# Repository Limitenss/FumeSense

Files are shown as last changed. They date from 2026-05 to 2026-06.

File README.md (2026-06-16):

# FumeSense

## Reviewer Message: please view the f3z file instead of the f3d, it contains the fully assembled case.

The FumeSense smart fume extractor is powered by an ESP32-S3. It features an Adafruit BME688 sensor that instantly detects harmful VOCs and activates a high-pressure fan to pull the fumes through an activated carbon filter. It also displays real-time data on a 2.4-inch LCD dashboard.

## Core Features

* **Auto-Detect & Remove:** Uses a gas to monitor the air. The moment VOCs from solder flux are detected, the system automatically ramps up the fan speed.
* **Hands-Free:** Both of your hands stay completely occupied with your soldering iron and components.
* **Filter Optimization:** Running a fan at 100% all the time unnecessarily wastes the active carbon compound by filtering clean room air. The auto-detect & remove feature ensures the carbon is only working when required, maximizing filter life.
* **Dashboard:** Features a Waveshare 2.4-inch LCD Module that displays fan-speed, and air info.
* **Manual Override:** Includes up and down buttons to let you instantly change the fan speed if you want to override the auto fan-speed.
* 

|Category |Component |Specific Model |Qty|Estimated Cost|Purpose |Link |
|---|---|---|---|---|---|---|
|Electronics |Microcontroller |Waveshare ESP32-S3-DEV-KIT-N8R8 |1  |$9.99 |Central brain; native pins avoid splicing |https://www.waveshare.com/esp32-s3-dev-kit-n8r8.htm?sku=24363 |
|Electronics |Display |Waveshare 2.4-inch LCD Module (240x320) |1  |$11.99 |Dashboard screen |https://www.waveshare.com/2.4inch-lcd-module.htm |
|Electronics |Air Quality Sensor |Adafruit BME688 |1  |$19.95 |Detects VOCs to trigger fan speed |https://www.adafruit.com/product/5046 |
|Airflow & Power |Extractor Fan |Noctua NF-F12 iPPC 3000 PWM, Heavy Duty Cooling Fan, 4-Pin, 3000 RPM (120mm, Black) |1  |$29.95 |Pulls fumes through filter |https://www.amazon.com/Noctua-NF-F12-iPPC-3000-PWM/dp/B00KFCRATC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|
|Airflow & Power |Filter Media |130x130x10mm Activated Carbon Sponge |1  |$8.54 |Traps solder flux |https://www.aliexpress.us/item/3256803786725180.html |
|Airflow & Power |Power Input |Adafruit Round Panel Mount Ext. Cable (30cm) |1  |$4.95 |Easy 24mm case mounting |https://www.adafruit.com/product/5607 |
|Airflow & Power |Power Splitter |5.5x2.1mm Female to Screw Terminal |1  |$3.99 |Splits 12V to fan and buck converter |https://www.amazon.com/Connector-Barrel-Adapter-Security-Camera/dp/B09S3S6RYC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 |
|Airflow & Power |Step-Down Converter |LM2596 DC-DC Buck Converter |1  |$7.99 |Drops 12V to 5V for ESP32 |https://www.amazon.com/Seloky-Converter-Adjustable-Electronic-Stabilizer/dp/B0DBVYP91F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 |
|Airflow & Power |Power Supply |12V DC Wall Adapter (2A) |1  |$7.97 |Main power source |https://www.amazon.com/Adapter-100-240V-Transformer-Charger-Security/dp/B091XSVV1Y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 |
|Hardware & Enclosure|Filament |PLA |1  |Owned |case material | |
|Hardware & Enclosure|Mounting Screws |M2 brass heat-set inserts |1  |$2.88 |Mounting Screws for Adafruit BME688 |https://www.aliexpress.us/item/3256805885174058.html |
|Hardware & Enclosure|Fan Inserts |M3 x 5mm Brass Heat-Set Inserts |4  |$5.95 |Anchors 120mm fan |https://www.adafruit.com/product/4255 |
|Hardware & Enclosure|Screen Inserts |M2.5 x 4mm Brass Heat-Set Inserts |4  |$7.39 |Mounts the 2.4-inch display |https://www.amazon.com/uxcell-Knurled-Printing-Threaded-Embedment/dp/B0CTCRQ94S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 |
|Hardware & Enclosure|Fan Screws |M3 x 30mm Socket Head Screws |4  |$9.99 |Clamps fan into M3 inserts |https://www.amazon.com/Alloy-Steel-Socket-Screws-Black/dp/B00W97RHMQ?th=1 |
|Hardware & Enclosure|Short Mounting Screws |M3 x 6mm Socket Head Screws |4  |$8.49 |Shallow mounting for case panels/accessories|https://www.amazon.com/Socket-Screws-Metric-Stainless-Machine/dp/B08976JTRX |
|Hardware & Enclosure|On/Off Switch |12V Round Rocker Switches |1  |$6.39 |its going to be the on/off switch. |https://www.amazon.com/DaierTek-Listed-Switches-Automotive-KCD1-5Pack/dp/B07S1MV462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 |
|Hardware & Enclosure|Wiring |24 AWG Silicone Wire |1  |$7.98 |Internal power routing |https://www.amazon.com/Silicone-Electrical-Colors-Stranded-Flexible/dp/B08F7CWMRX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 |
|Hardware & Enclosure|12mm momentary push buttons|12mm momentary push buttons |1  |$7.99 |up/down buttons to override fan control |https://www.amazon.com/Gebildet-Prewired-Waterproof-Momentary-Stainless/dp/B08L49F7DV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 |
|Total | | | |$162.38 | | |

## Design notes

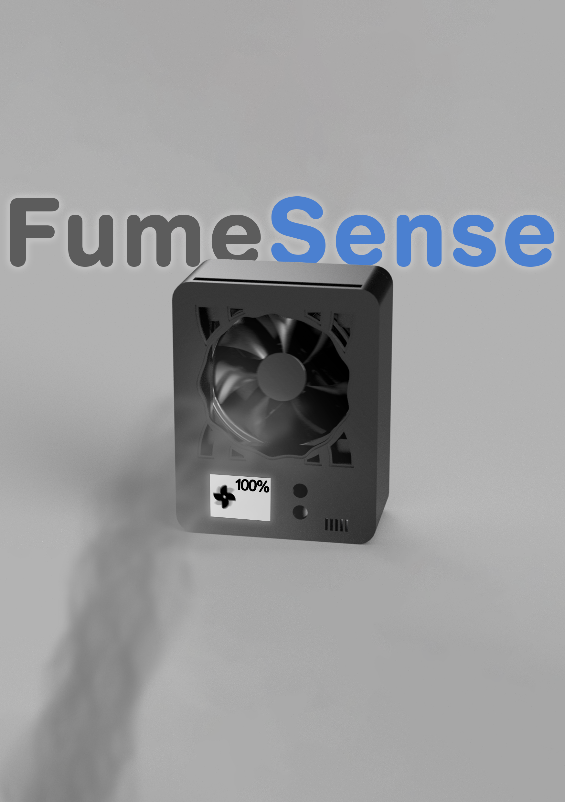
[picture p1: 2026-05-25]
Untitled-1.png

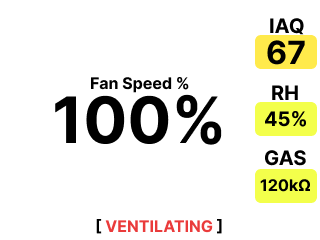
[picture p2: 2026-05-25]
UI_Mockups/Frame 1.png

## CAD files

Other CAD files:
Case/FumeSense.f3d
Case/FumeSense.f3z

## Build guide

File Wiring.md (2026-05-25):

## Pin Mapping

| Component | Component Pin | ESP32-S3 GPIO |
| :--- | :--- | :--- |
| **BME688 Sensor** | SCL | **GPIO 4** |
| | SDA | **GPIO 5** |
| **Waveshare 2.4" LCD**| MOSI | **GPIO 11** |
| | SCLK / CLK | **GPIO 12** |
| | CS | **GPIO 10** |
| | DC | **GPIO 9** |
| | RST | **GPIO 14** |
| | BL | **GPIO 21** |
| **Noctua Fan** | PWM Signal | **GPIO 15** |
| | Tachometer| **GPIO 16** |
| **Up Button** | Prong 1 | **GPIO 6** |
| **Down Button**| Prong 1 | **GPIO 7** |

## Power Rail

* **Main Input:** 12V DC Barrel Jack → 12V Heavy-Duty Rocker Switch (Hard Cut)
* **High-Power Rail (12V):** Feeds Noctua Industrial Fan (+) and LM2596 Buck Converter (IN+)
* **Logic-Power Rail (5V):** LM2596 (OUT+) → ESP32-S3 (5V Pin) to power the microcontroller.
* **Sensor/Screen Rail (3.3V):** Powered by the ESP32-S3 3.3V regulator output pins.
